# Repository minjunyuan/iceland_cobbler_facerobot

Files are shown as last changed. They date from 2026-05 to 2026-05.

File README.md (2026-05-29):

# Iceland Cobbler Face Robot

这是一个基于 Blender 开源角色模型进行二次设计的人脸机器人项目。项目内容包括机器人内部表情机构、脸部外壳、硅胶皮肤模具，以及用于展示的 STL 文件。

除明确注明来源的 Blender Studio Einar 参考模型外，本文展示的机器人机械结构、外壳、硅胶皮肤模具和实物制作均为自制。机构驱动舵机使用 MG90D。

## 项目状态

本文主要记录设计思路、关键流程和阶段性成果，没有对内部结构设计的全部细节逐一展开。若对某个结构、制作步骤或文件内容有疑问，可以通过 GitHub Issues 交流。

实际制作人脸机器人时会遇到大量与材料、装配公差、驱动行程、硅胶成型和外壳避让相关的具体问题，需要读者结合自己的加工条件和设计目标自行调整。本项目目前处于搁置状态，现有结构仍存在一些需要继续优化的问题，但整体设计方向接近常见人脸机器人和仿生表情机构的主流思路，可作为外观机构、面壳设计和硅胶模具设计的参考案例。

## 项目结构

```text
.
├─ full_assembly_stl/   # 所有设计元素的 STL 文件
├─ images/              # 项目图片、渲染图、过程图
└─ README.md
```

## 1. 设计对象

本项目的设计对象来源于 Blender Studio 的开源角色模型：[Einar](https://studio.blender.org/characters/einar/v1/)。

这个模型本身有完整的头部建模，并且包含独立的眼睛、牙齿和舌头模型。由于这些部分之间的相对位置已经确定，因此非常适合作为人脸机器人外观设计、机构空间规划和硅胶皮肤制作的参考对象。

<p>
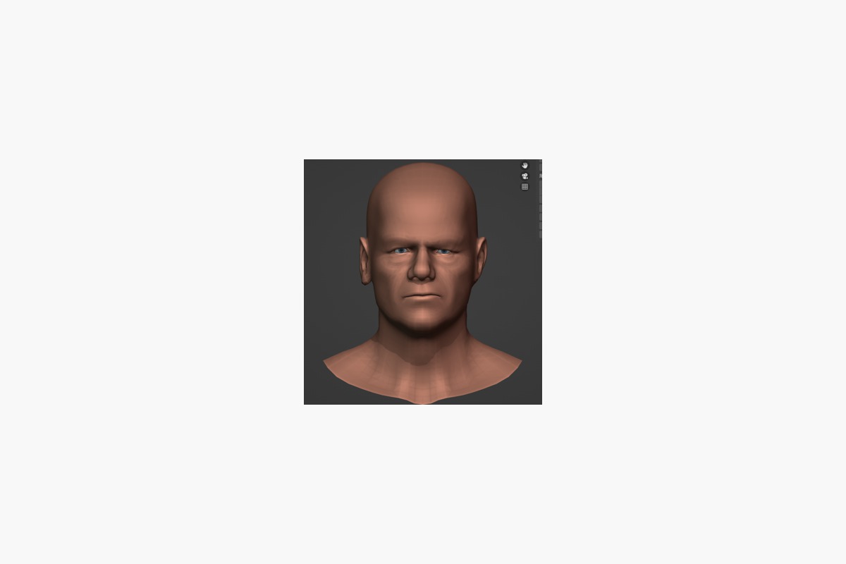
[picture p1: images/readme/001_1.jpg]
Einar 参考图 1
  
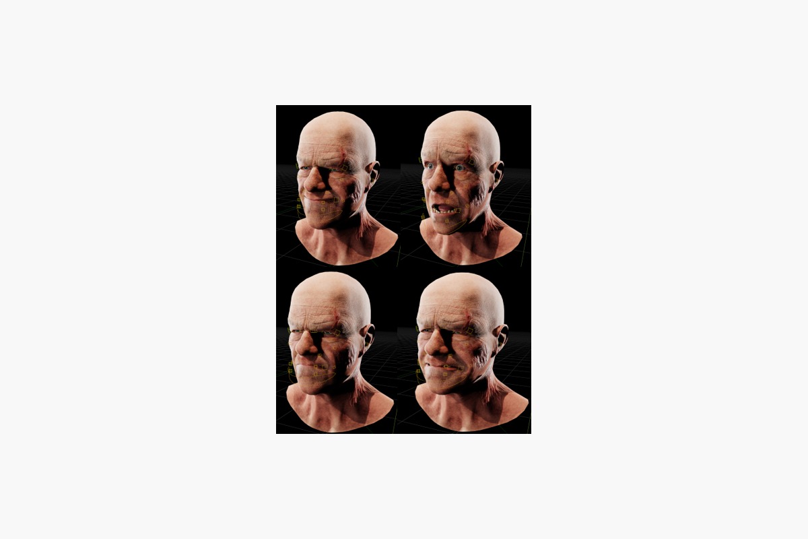
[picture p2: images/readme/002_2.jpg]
Einar 参考图 2
  
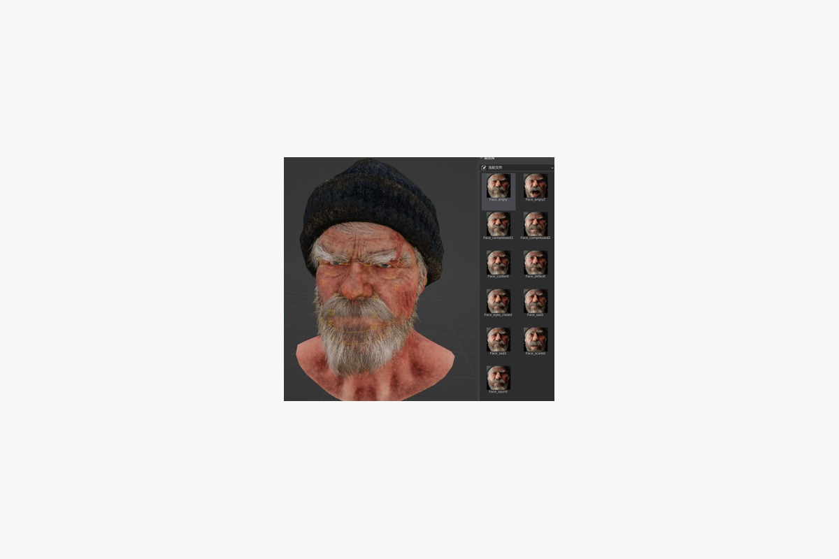
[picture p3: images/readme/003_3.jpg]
Einar 参考图 3
  
</p>

<p>
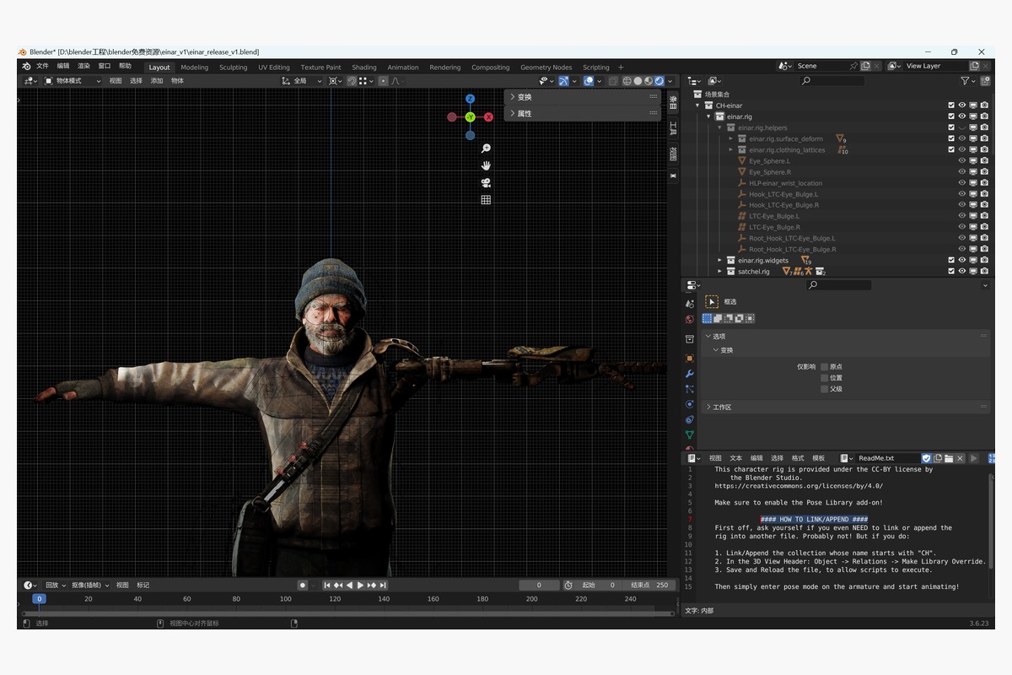
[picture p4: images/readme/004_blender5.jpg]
Blender 参考模型 1
  
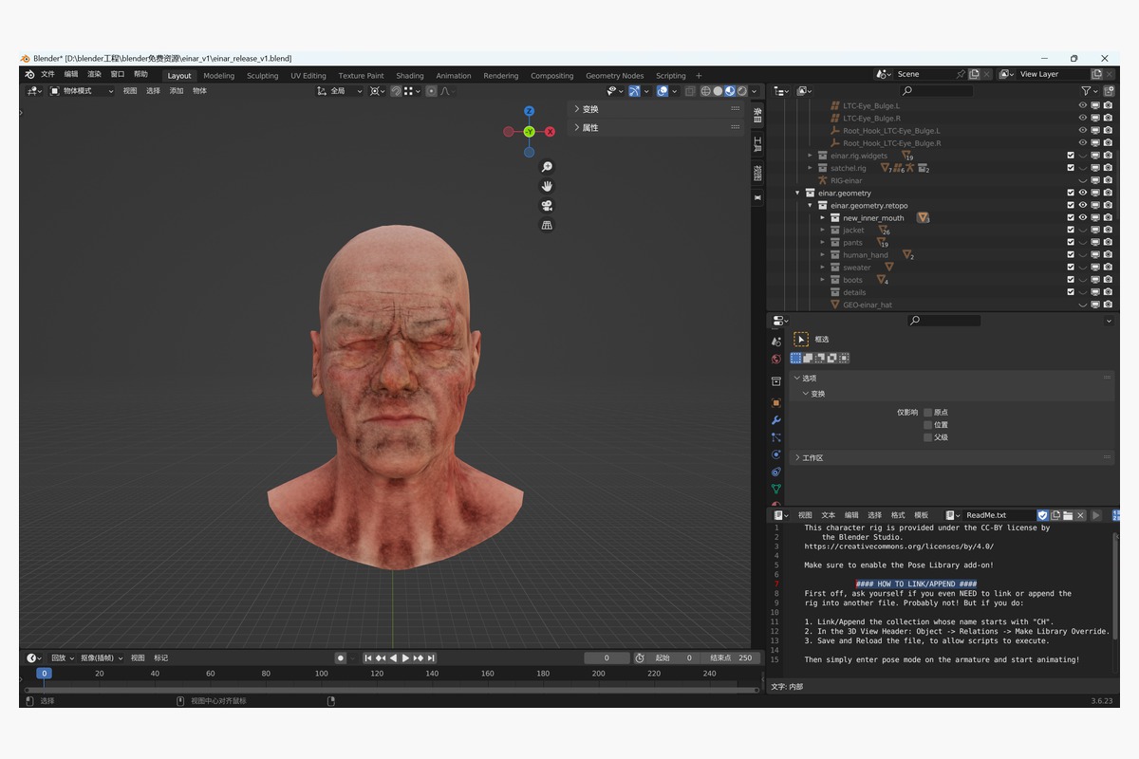
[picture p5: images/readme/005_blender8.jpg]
Blender 参考模型 2
  
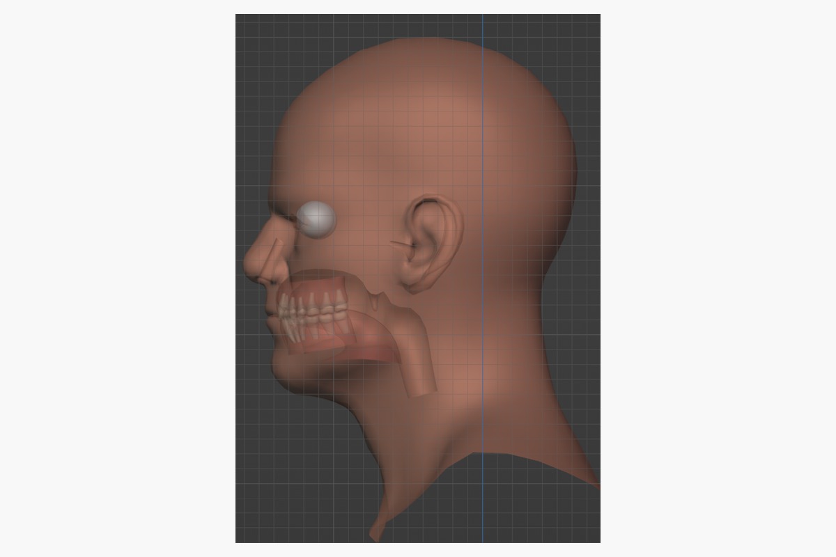
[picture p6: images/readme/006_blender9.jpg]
Blender 参考模型 3
  
</p>

## 2. 结构设计

结构部分采用模块化设计，目的是方便拆装、调试和后续修改。主体可以分为眉部、眼部和嘴部，其中嘴部又分为上颚部分和下颚部分。

眉部机构会预留一部分脸颊和鼻子拉线的空间；眼部机构用于支撑和控制眼睛区域；嘴部机构则承担上下颚和口腔区域的表情运动。

本项目中使用的舵机型号为 MG90D。模块化设计可以让舵机、连杆、壳体和硅胶皮肤的设计相互独立，便于单独修改和迭代。

### 整体设计展示

<p>
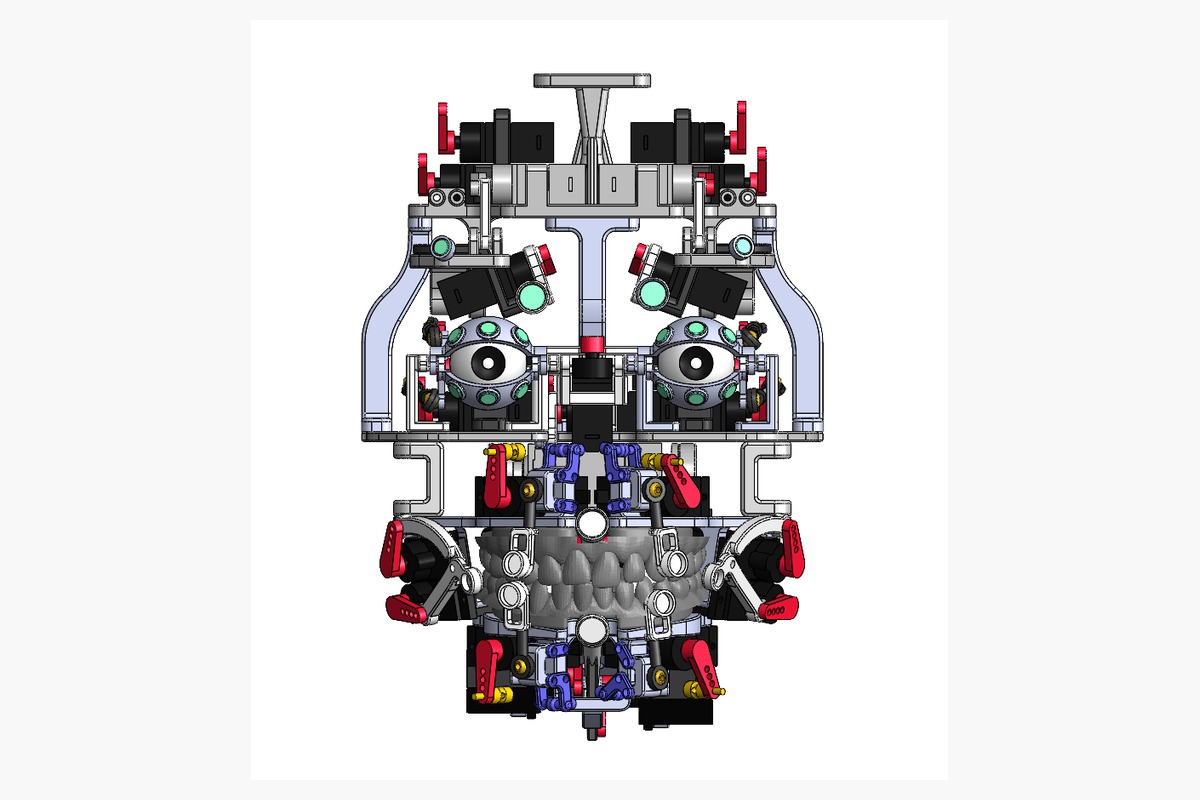
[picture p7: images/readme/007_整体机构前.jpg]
整体机构前视图
  
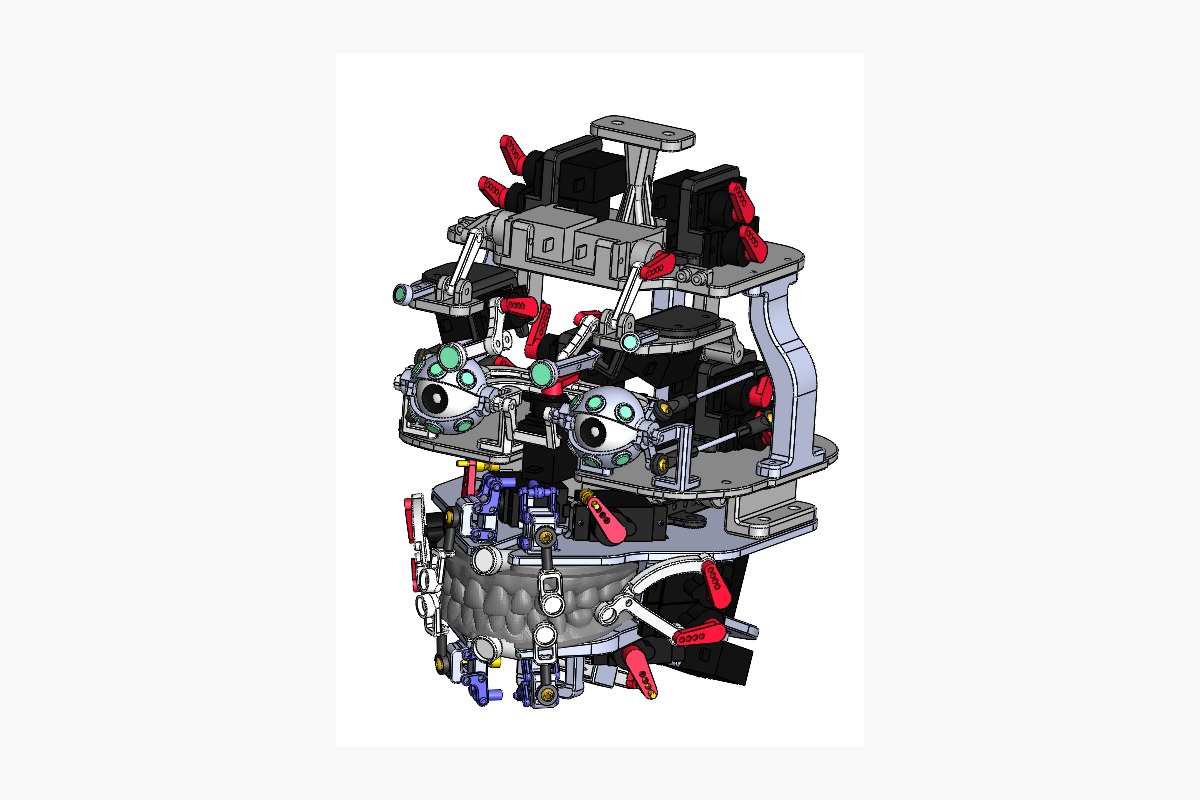
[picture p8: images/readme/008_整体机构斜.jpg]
整体机构斜视图
  
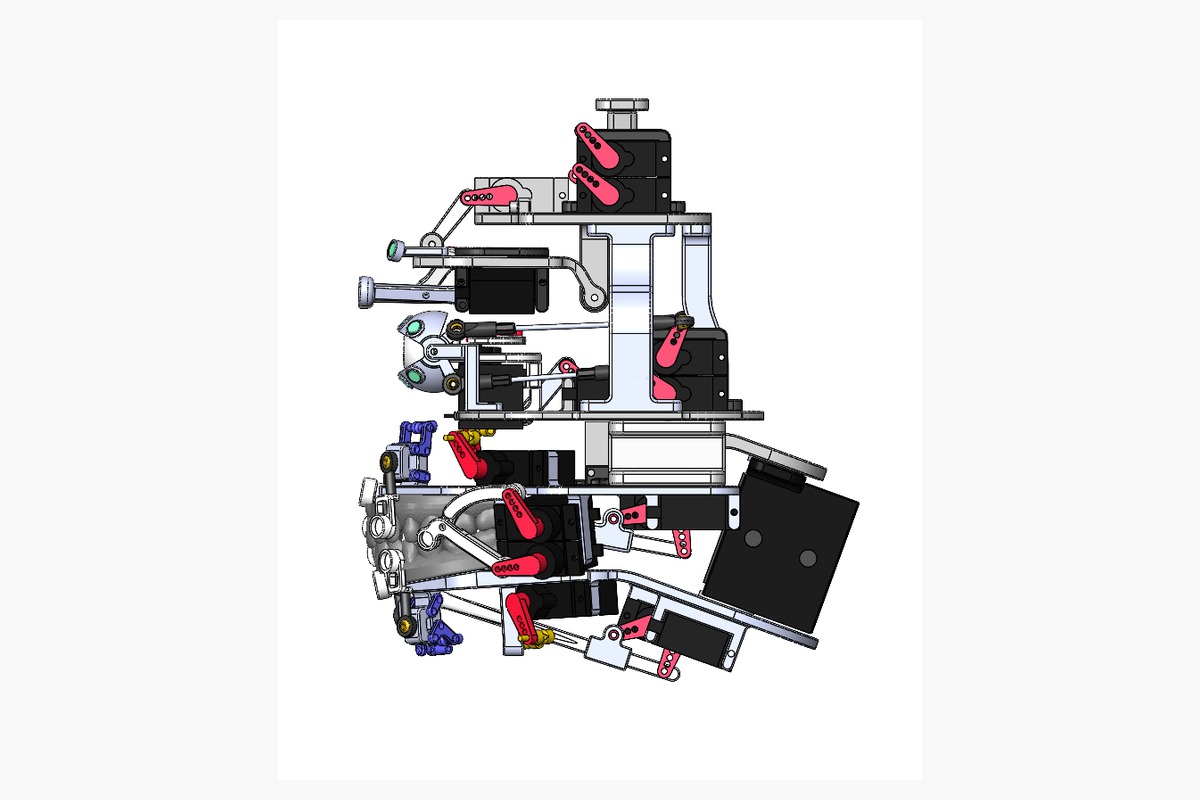
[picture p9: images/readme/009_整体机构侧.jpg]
整体机构侧视图
  
</p>

<p>
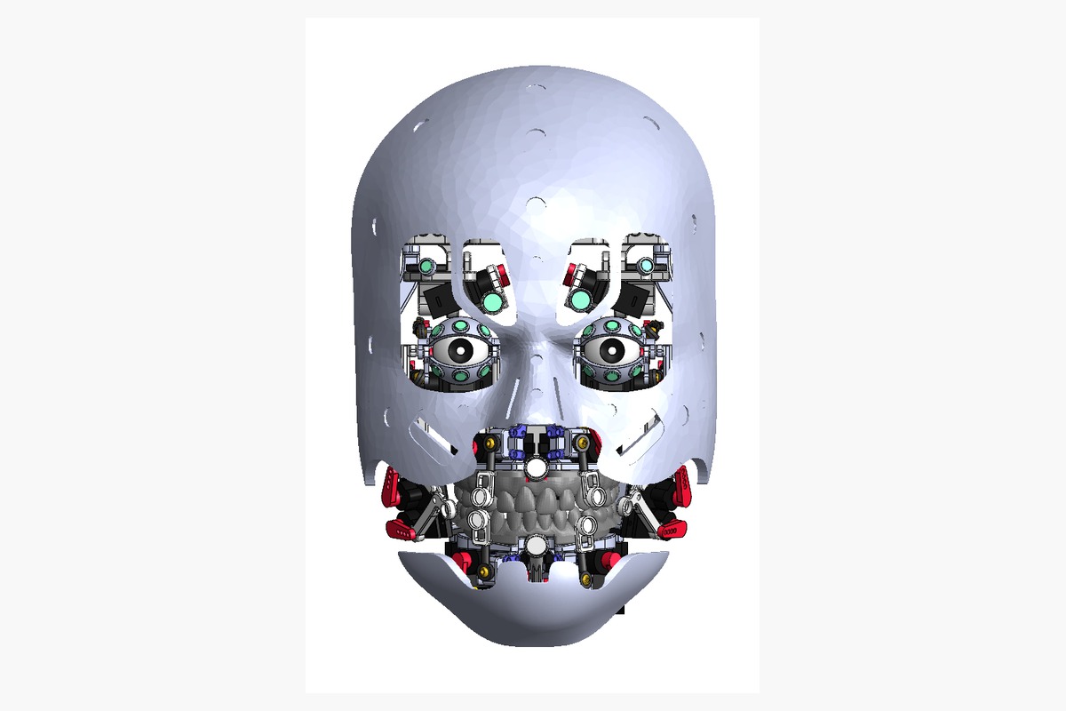
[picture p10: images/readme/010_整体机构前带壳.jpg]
整体机构前视图带壳
  
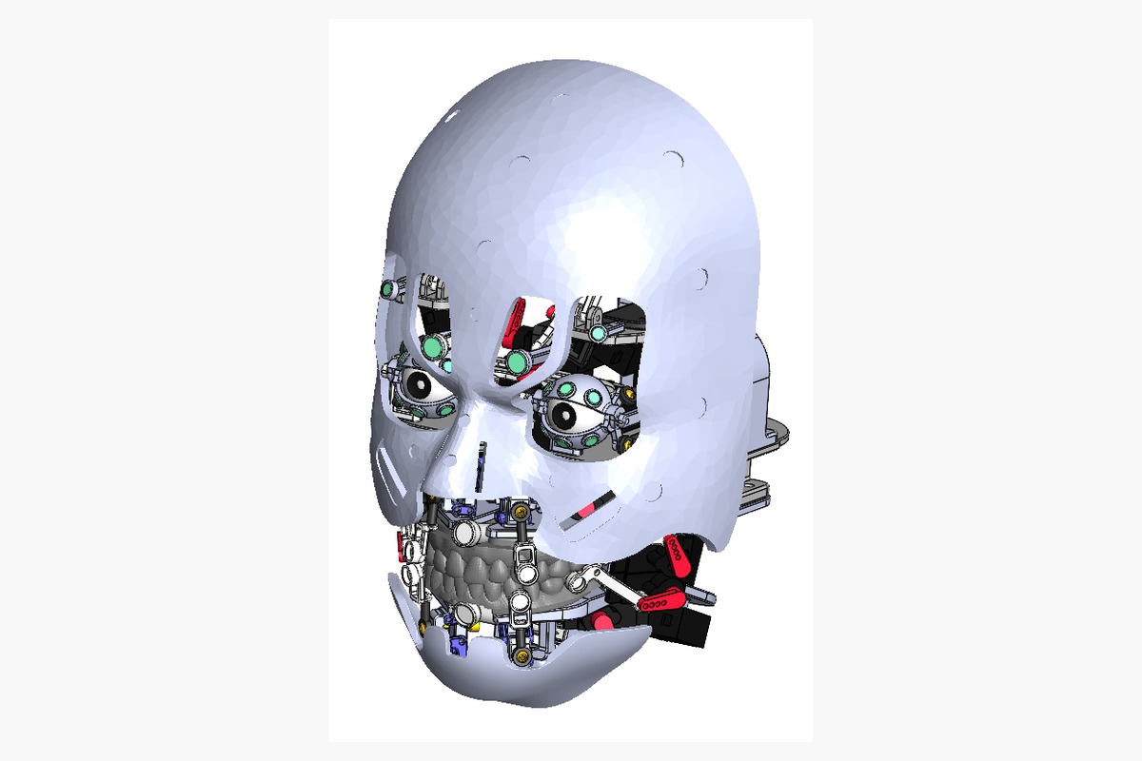
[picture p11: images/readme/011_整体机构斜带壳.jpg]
整体机构斜视图带壳
  
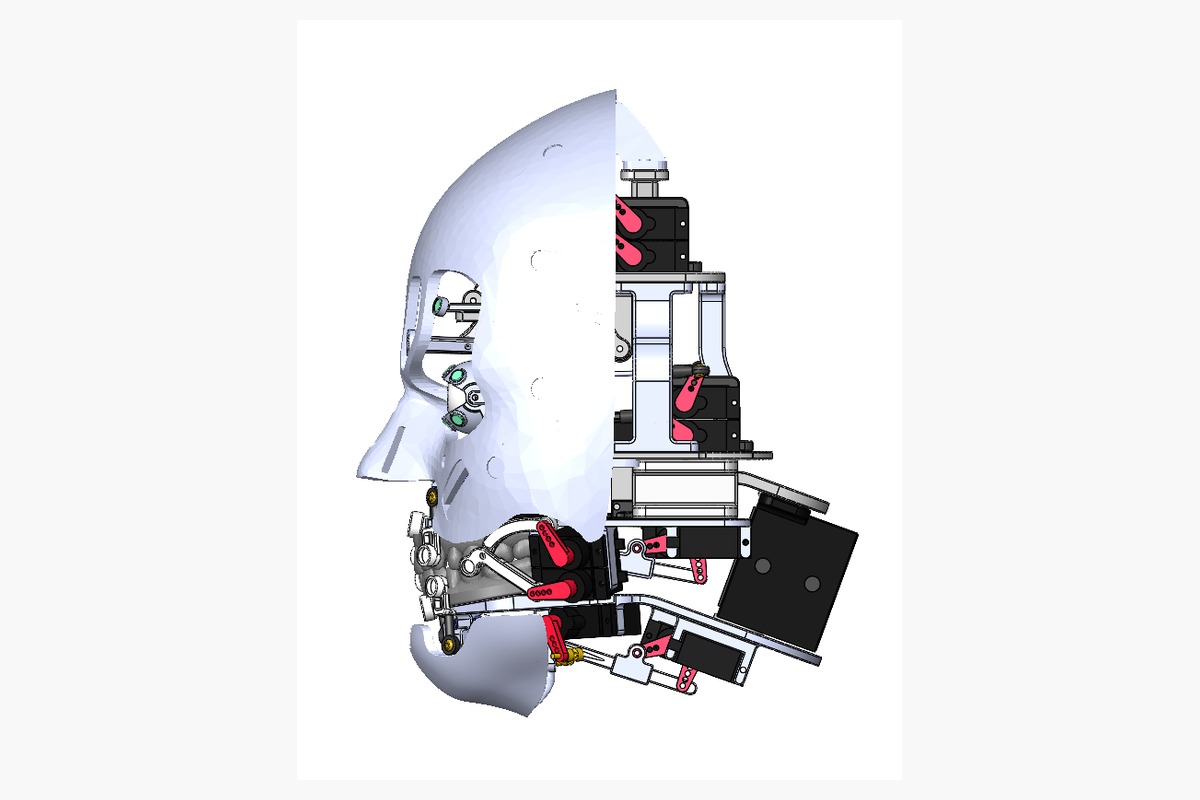
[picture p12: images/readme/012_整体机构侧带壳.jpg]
整体机构侧视图带壳
  
</p>

<p>
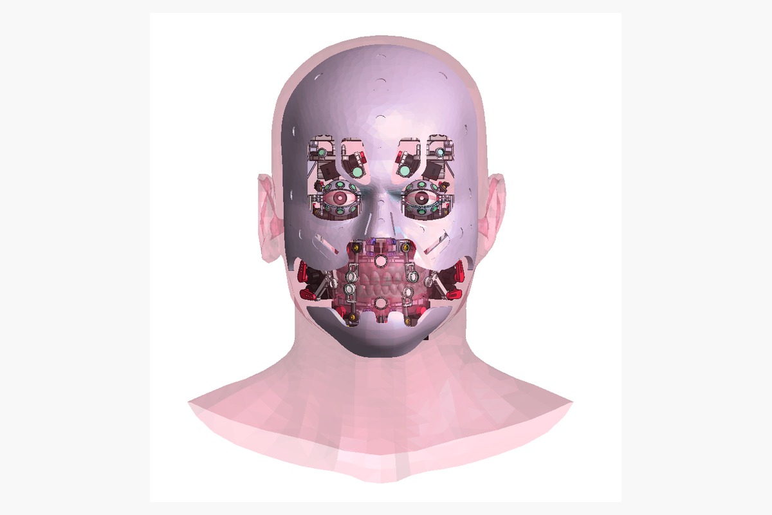
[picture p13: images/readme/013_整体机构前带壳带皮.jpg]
整体机构前视图带壳带皮
  
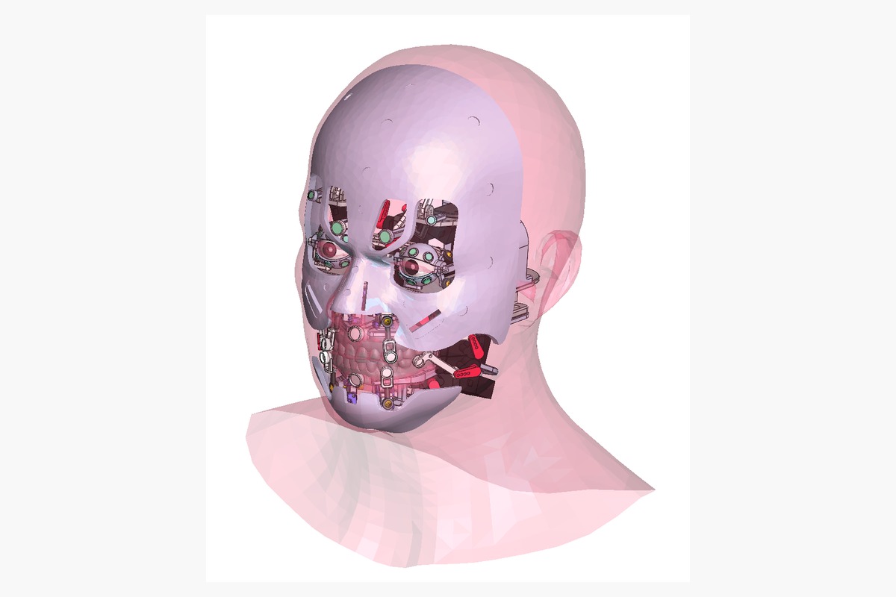
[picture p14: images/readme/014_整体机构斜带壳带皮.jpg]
整体机构斜视图带壳带皮
  
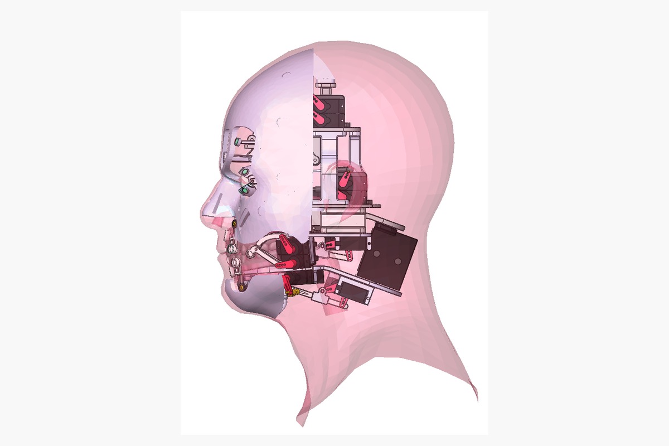
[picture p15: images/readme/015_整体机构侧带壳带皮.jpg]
整体机构侧视图带壳带皮
  
</p>

### 眉部机构

<p>
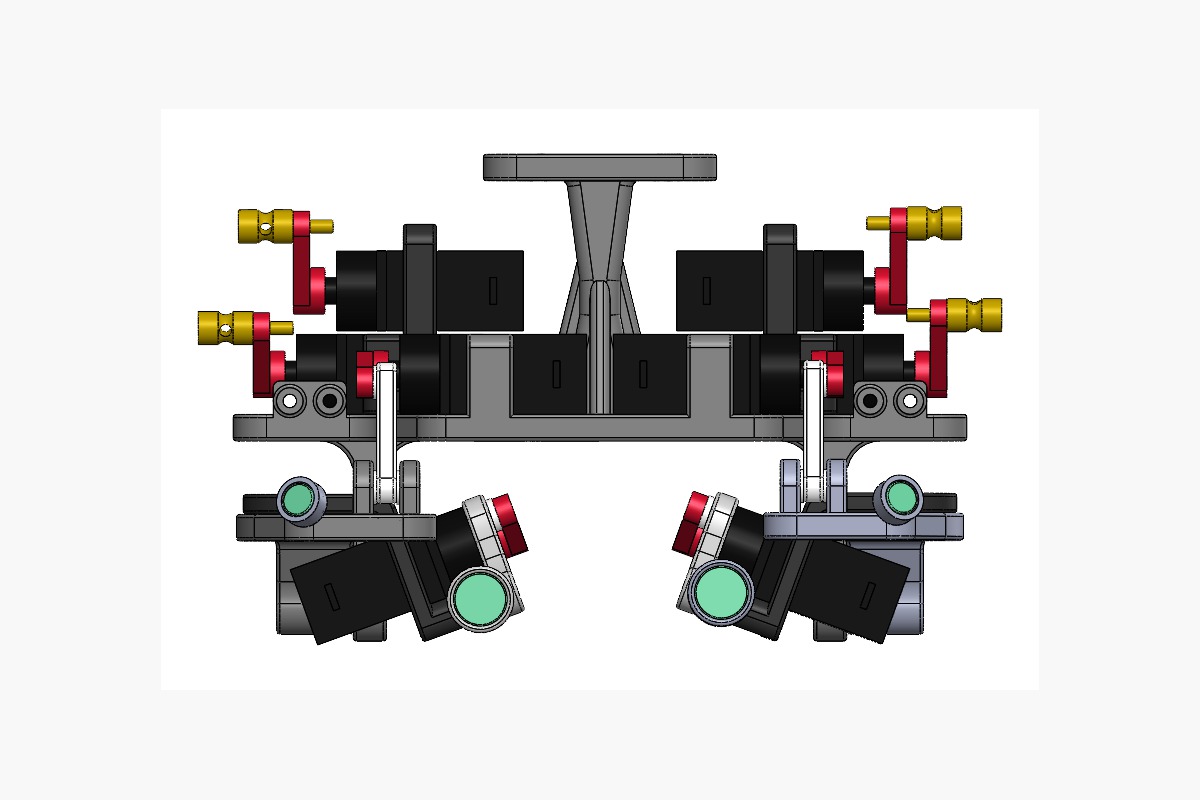
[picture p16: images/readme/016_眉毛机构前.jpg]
眉毛机构前视图
  
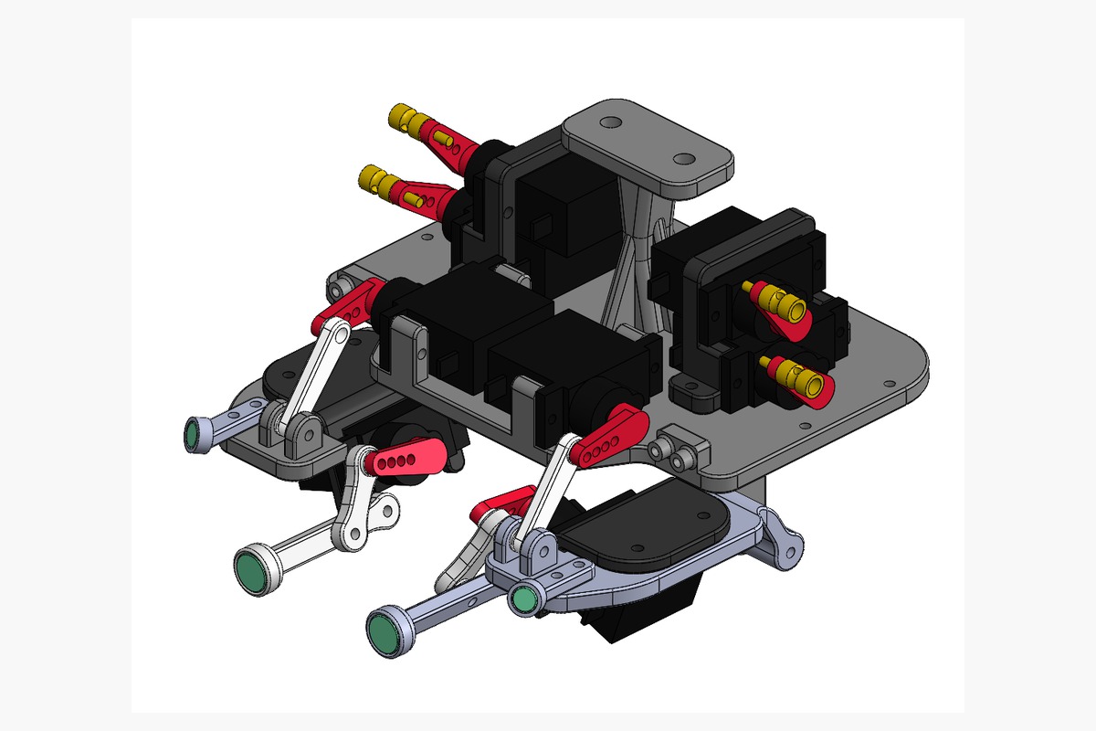
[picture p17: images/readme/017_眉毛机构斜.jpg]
眉毛机构斜视图
  
</p>

### 眼部机构

<p>
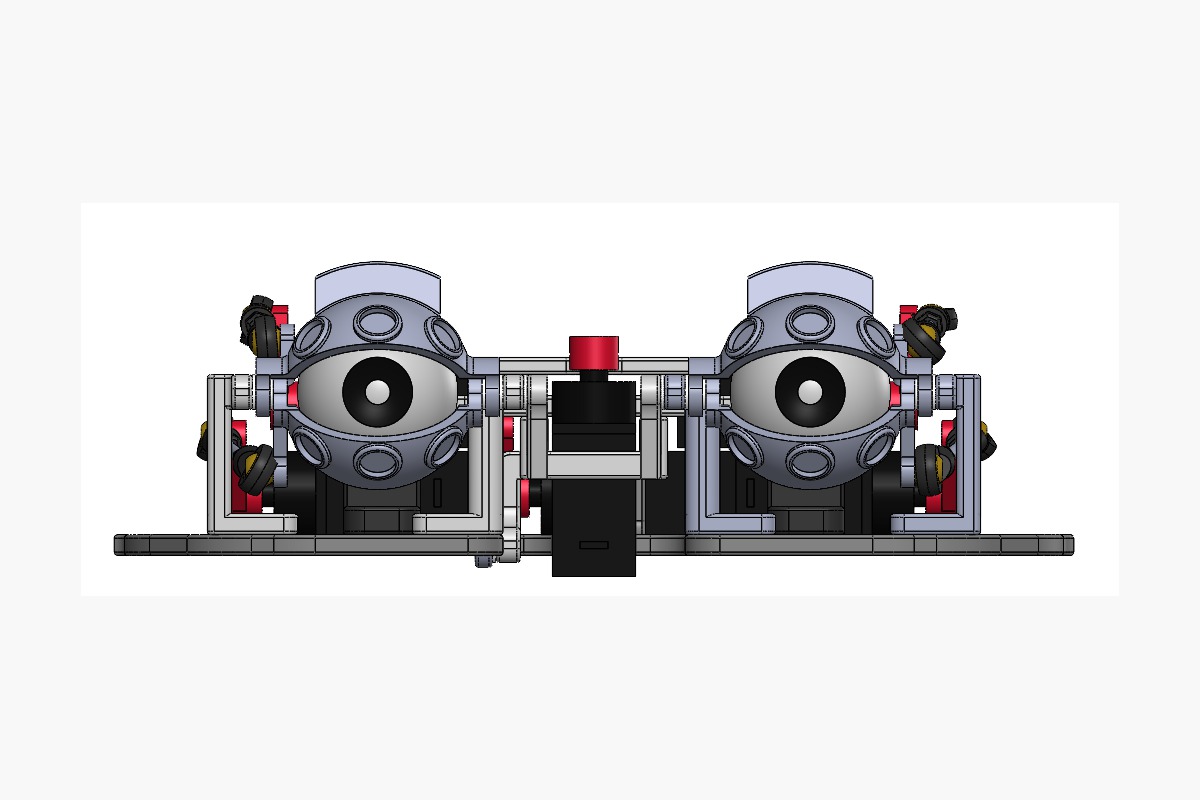
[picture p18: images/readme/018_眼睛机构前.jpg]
眼睛机构前视图
  
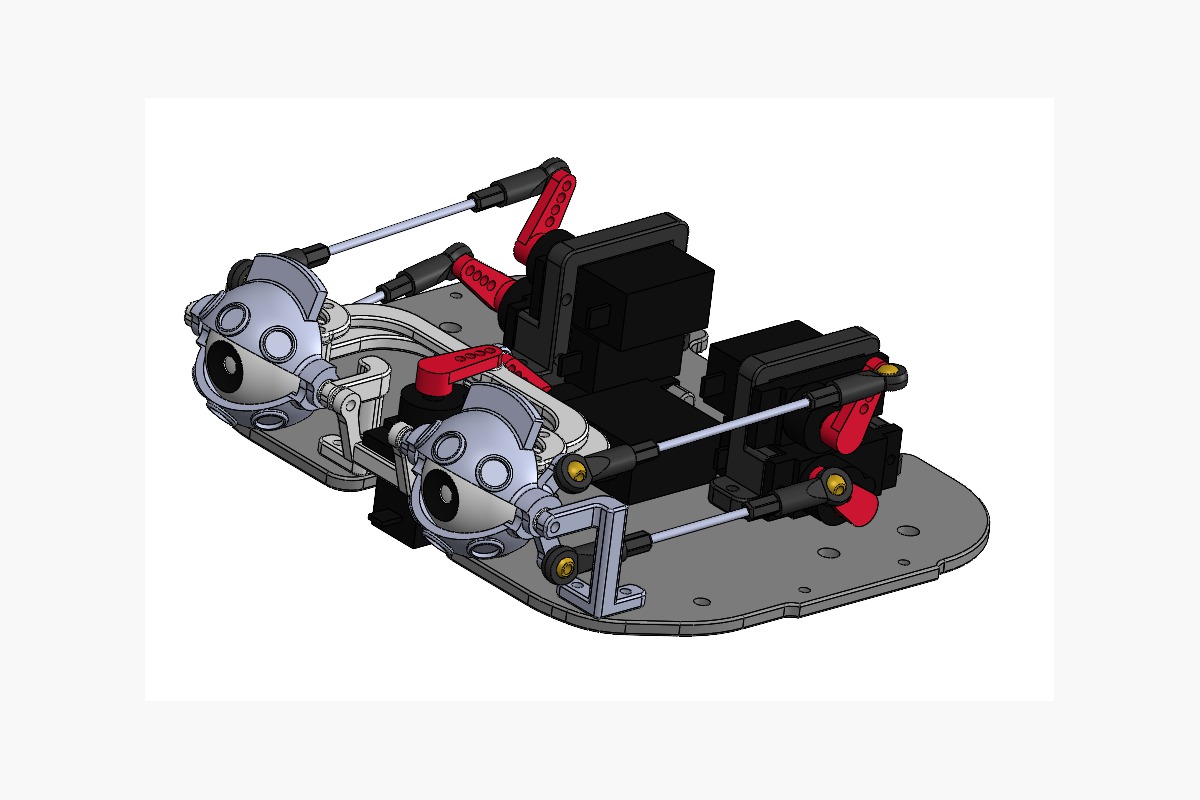
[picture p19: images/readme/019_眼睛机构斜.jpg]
眼睛机构斜视图
  
</p>

### 嘴部机构

<p>
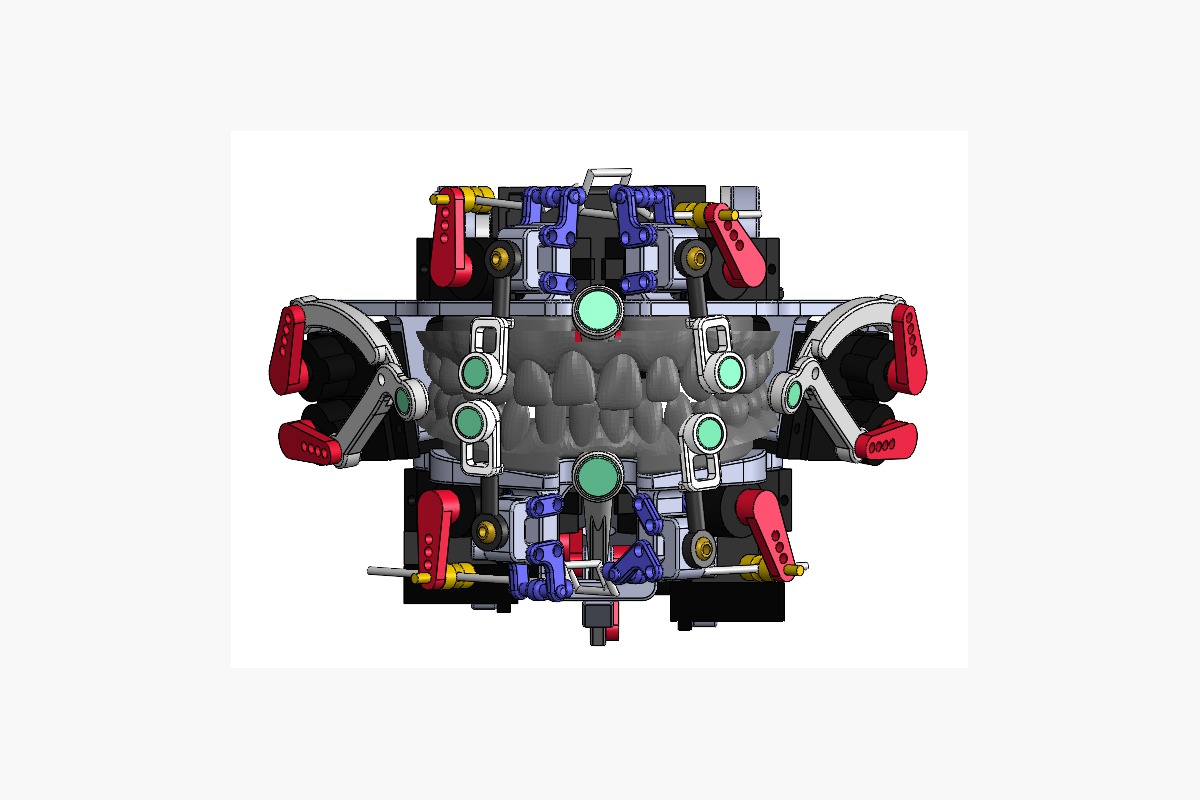
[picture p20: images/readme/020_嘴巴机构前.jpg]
嘴巴机构前视图
  
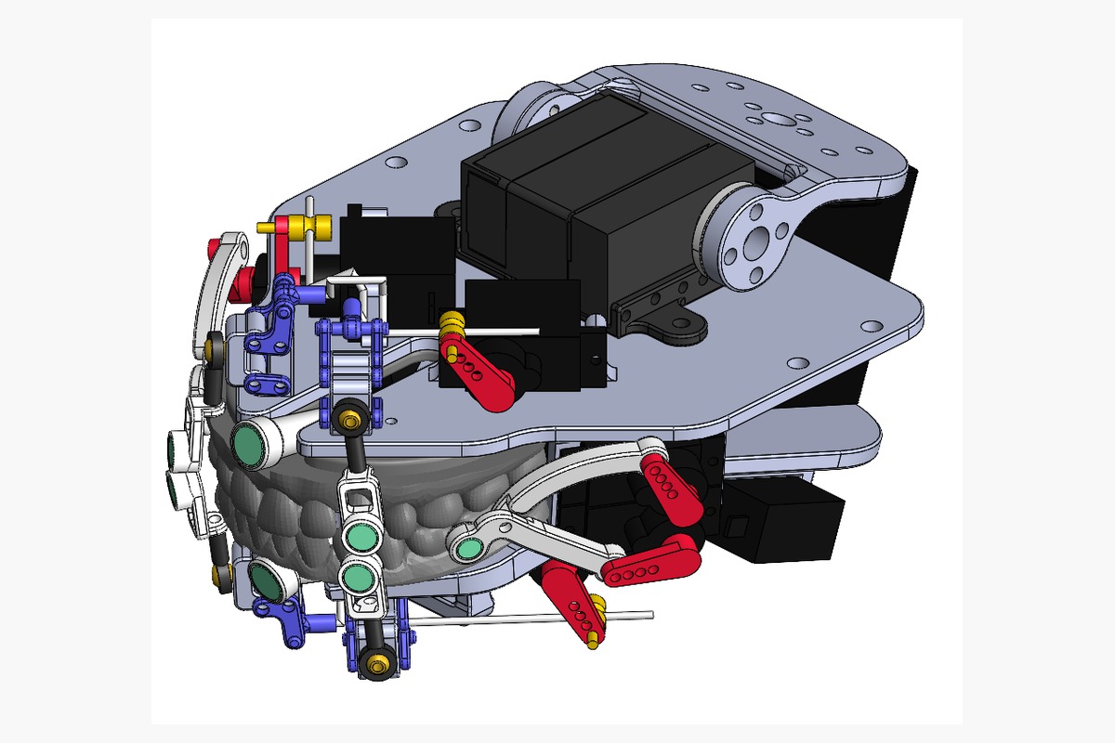
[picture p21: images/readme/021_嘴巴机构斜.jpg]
嘴巴机构斜视图
  
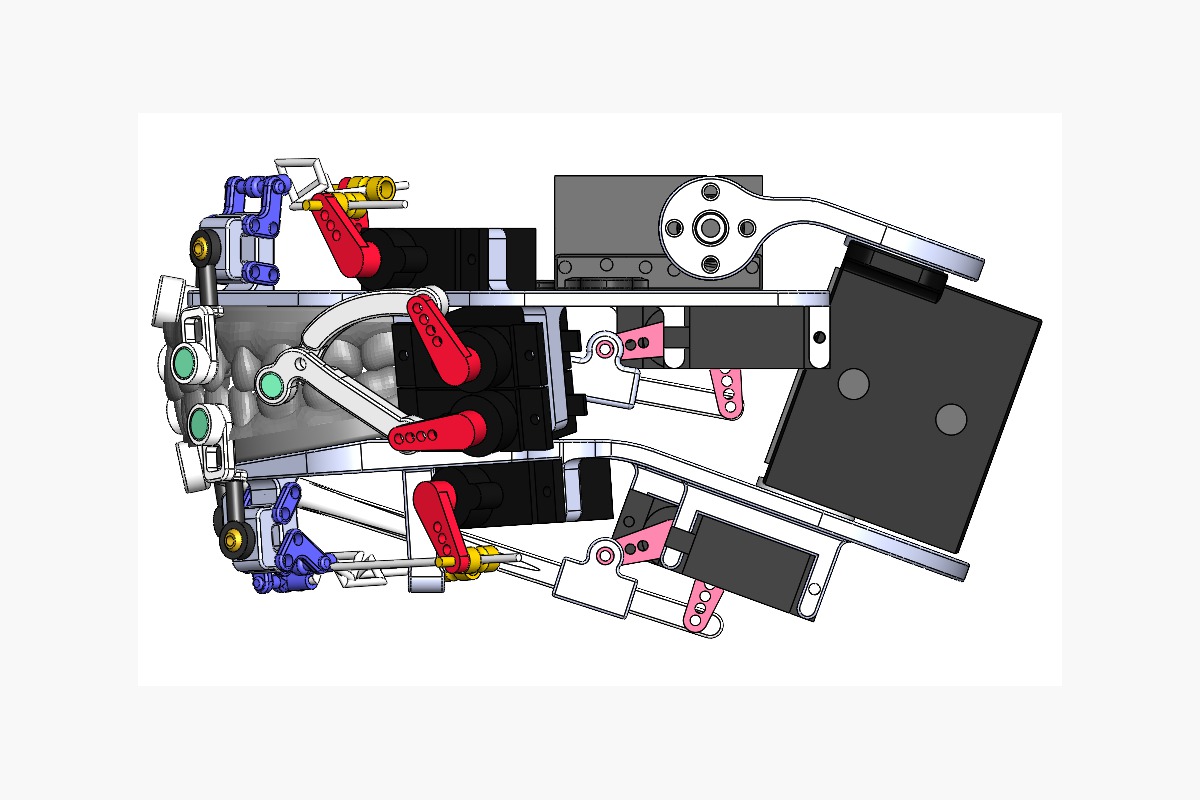
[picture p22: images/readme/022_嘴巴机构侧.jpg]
嘴巴机构侧视图
  
</p>

### 实物图

<p>
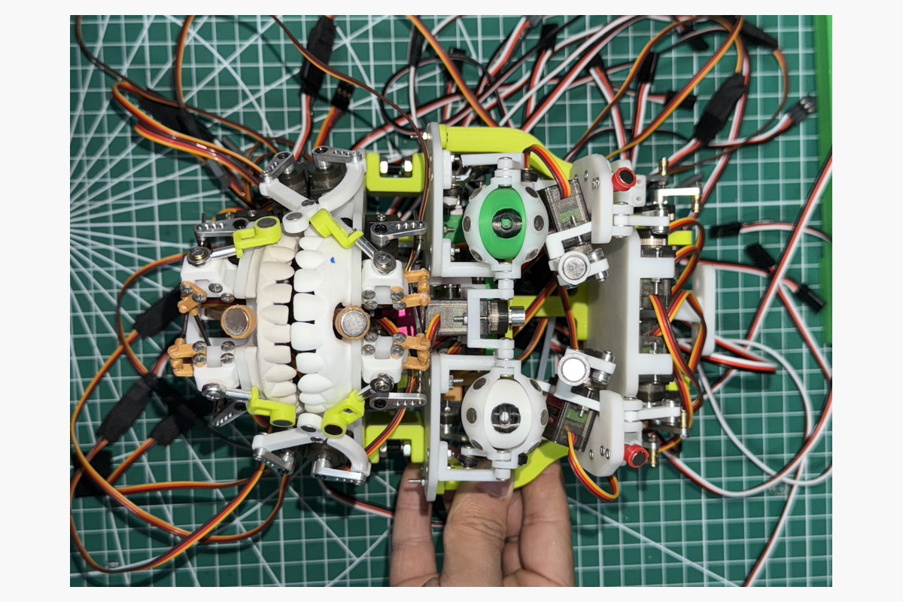
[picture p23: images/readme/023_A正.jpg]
实物图 A 正面
  
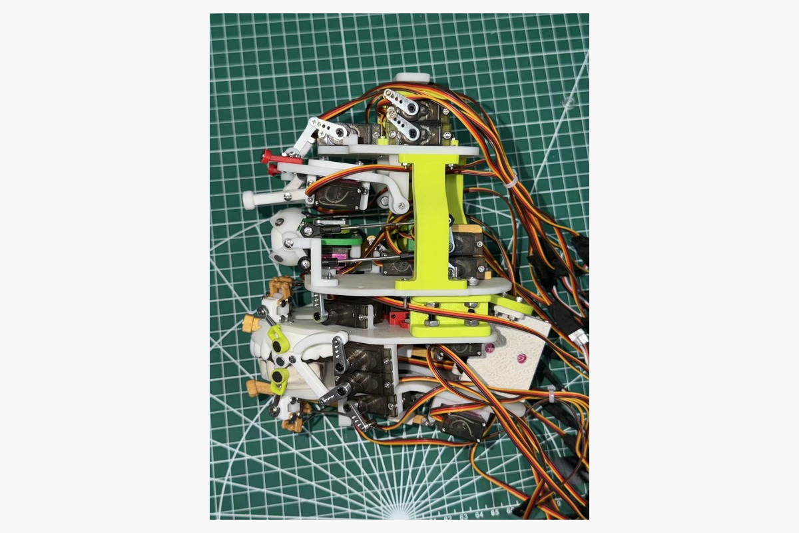
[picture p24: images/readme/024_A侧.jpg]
实物图 A 侧面
  
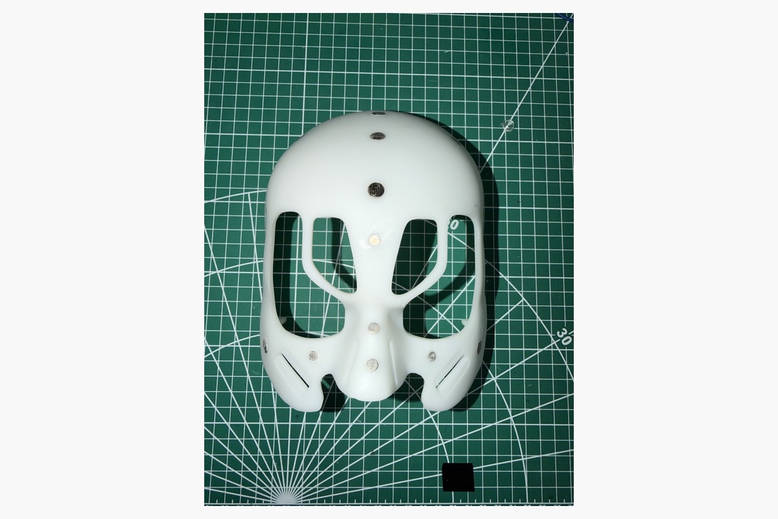
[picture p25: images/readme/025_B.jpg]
实物图 B
  
</p>

### STL 文件说明

`full_assembly_stl/` 中放置了所有设计元素的 STL 文件。将这些 STL 导入任何可以观察 STL 的软件中，例如 Blender，可以显示正确的相对位置。

在本项目中，Blender 不只是展示工具，后续也用于设计机器人脸部外壳，以及设计硅胶皮肤制作所需要的模具。

<p>
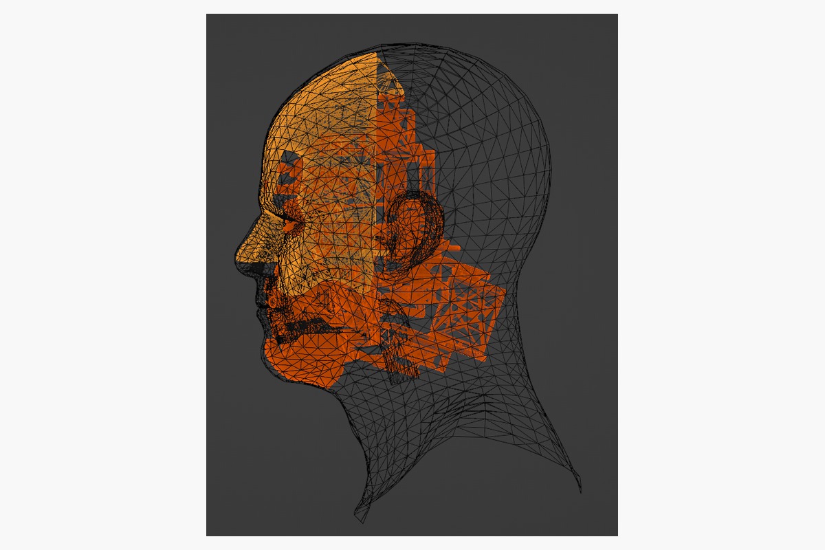
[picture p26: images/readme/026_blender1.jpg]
STL 导入 Blender 1
  
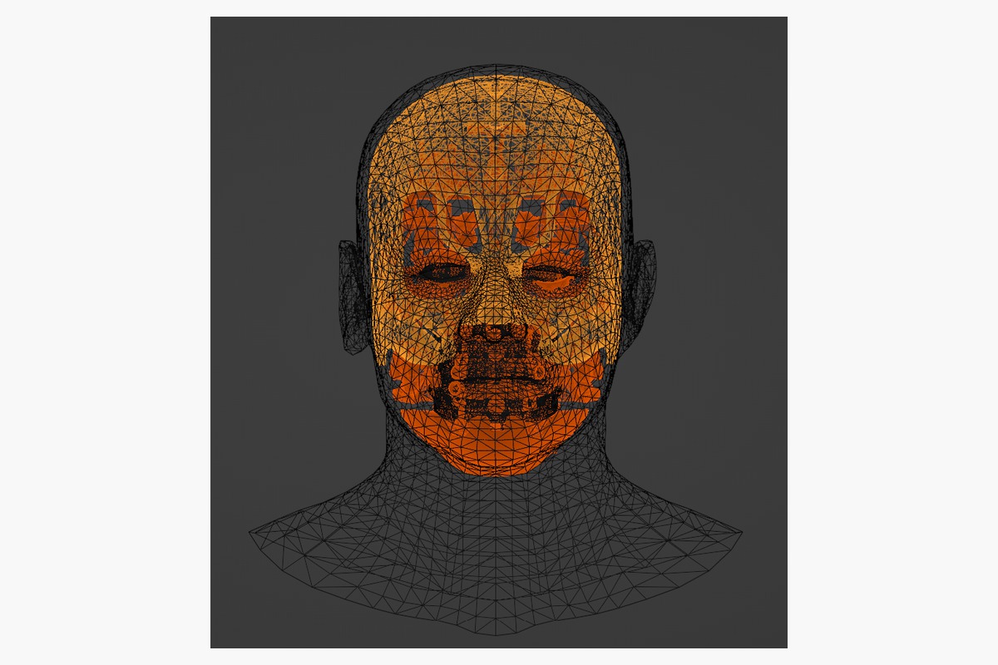
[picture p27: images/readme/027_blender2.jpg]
STL 导入 Blender 2
  
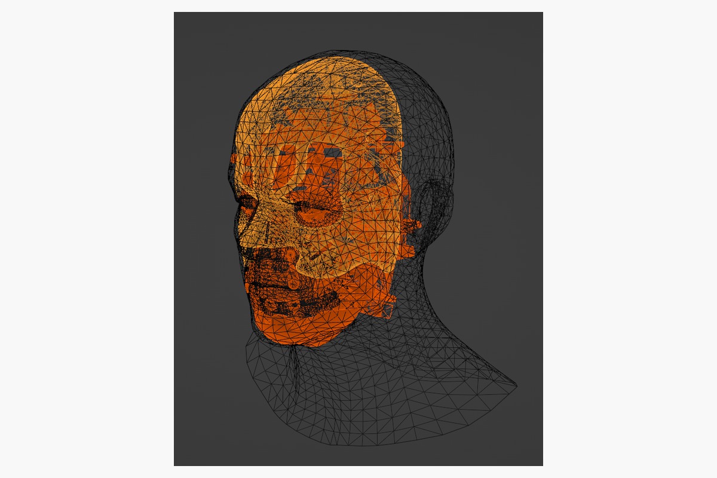
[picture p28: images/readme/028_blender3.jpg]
STL 导入 Blender 3
  
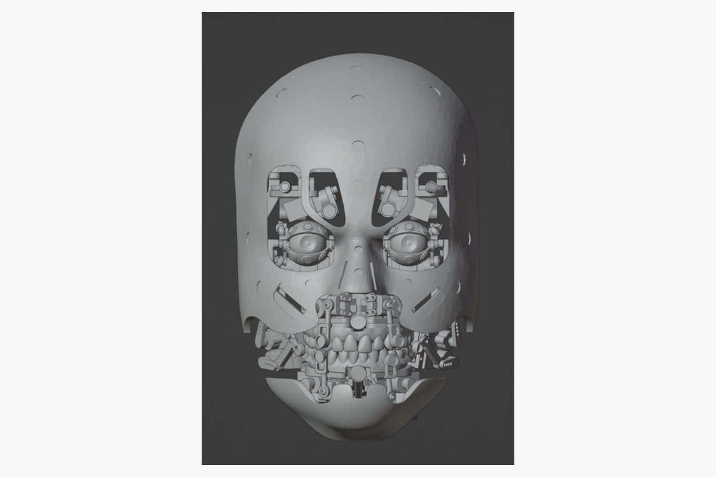
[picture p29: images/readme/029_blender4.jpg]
STL 导入 Blender 4
  
</p>

## 3. 机器人脸部外壳设计（Blender）

### 3.1 参考人物模型处理

Blender 开源模型中可以获得无厚度的参考人物模型。机器人脸部外壳不需要明显的皱纹，同时对称、平整的表面更适合后续设计和加工，所以这里对原始模型进行了平滑处理。

<p>
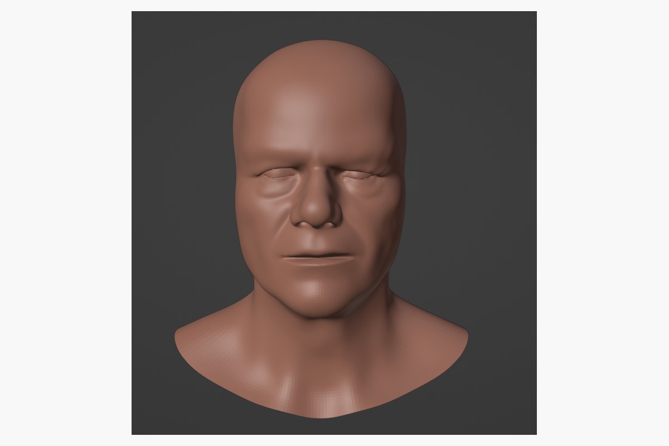
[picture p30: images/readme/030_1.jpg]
参考模型处理 1
  
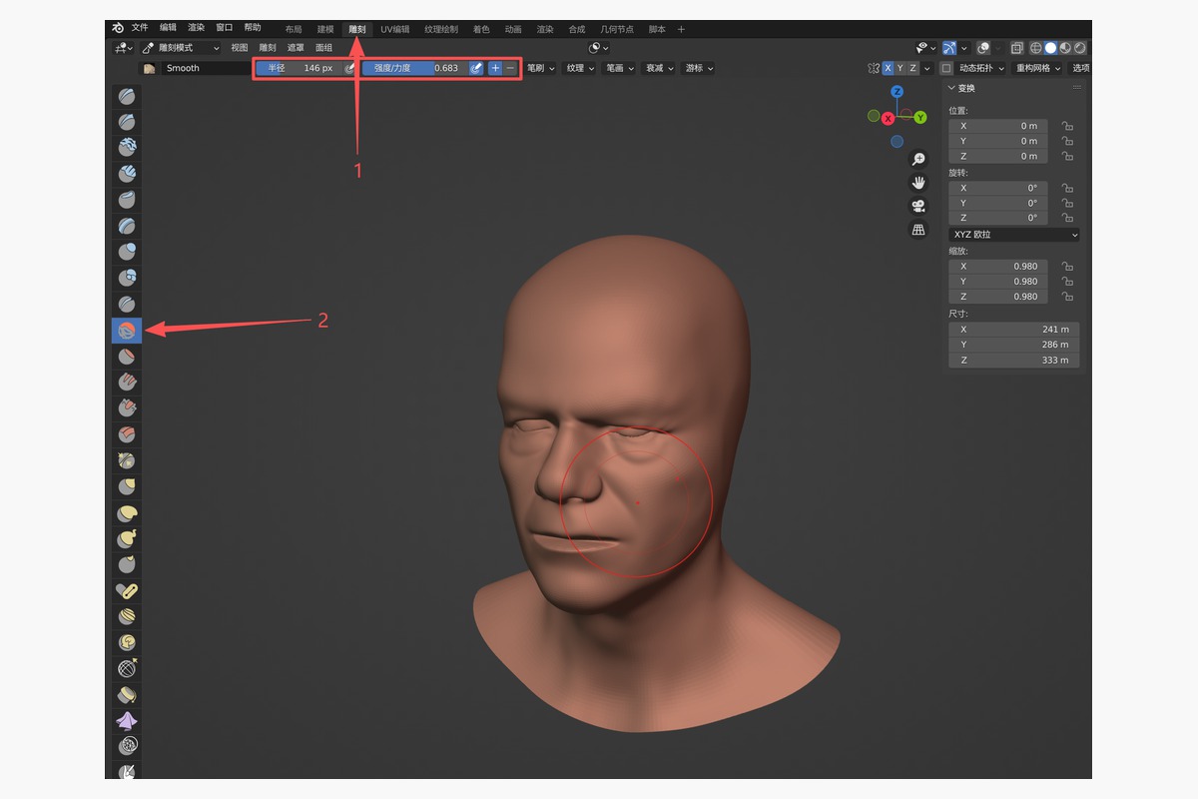
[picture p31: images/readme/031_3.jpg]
参考模型处理 2
  
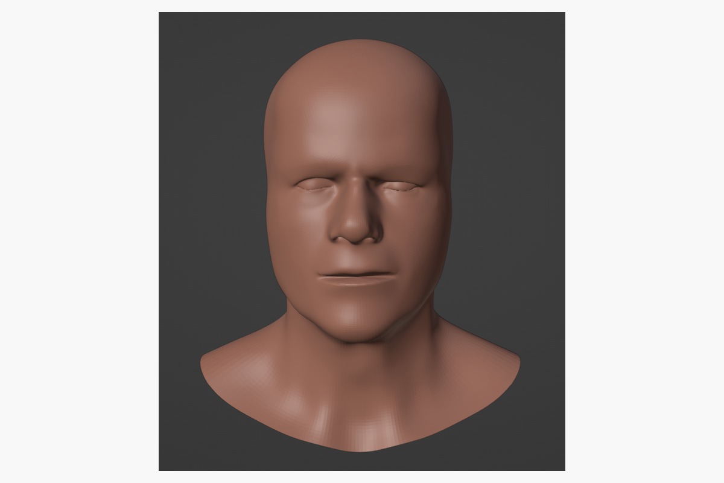
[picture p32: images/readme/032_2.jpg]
参考模型处理 3
  
</p>

### 3.2 外壳厚度

外壳需要一定厚度。在 Blender 中，固定厚度通常可以通过修改器中的“实体化”完成，厚度选项可以修改壳体厚度，偏移量可以决定实体化方向。

需要注意两点：

- Blender 中的单位 `m` 在当前显示中对应 `mm`。
- 有些区域，例如眼睛附近，曲率比较大，实体化后可能出现局部穿模。但在制作外壳时不一定需要担心，因为这些区域后续通常会被挖掉，用来给运动构件留空间。

<p>
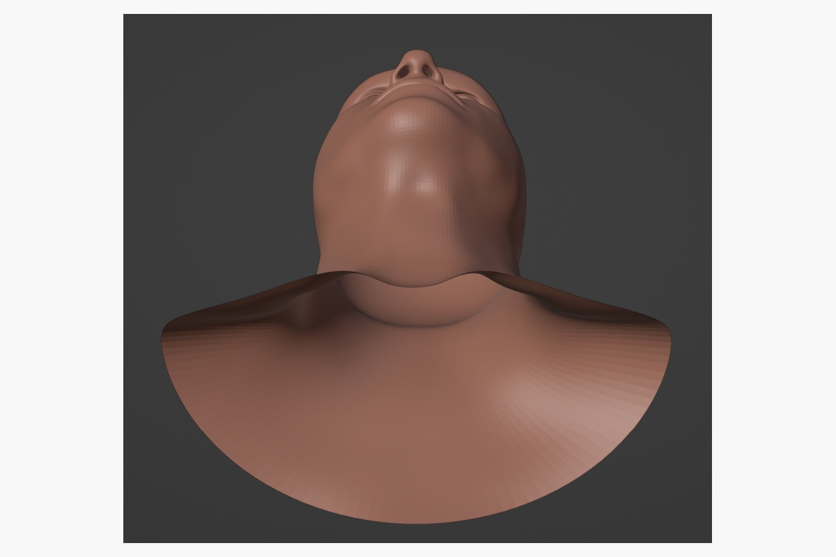
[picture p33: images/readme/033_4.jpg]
实体化厚度 1
  
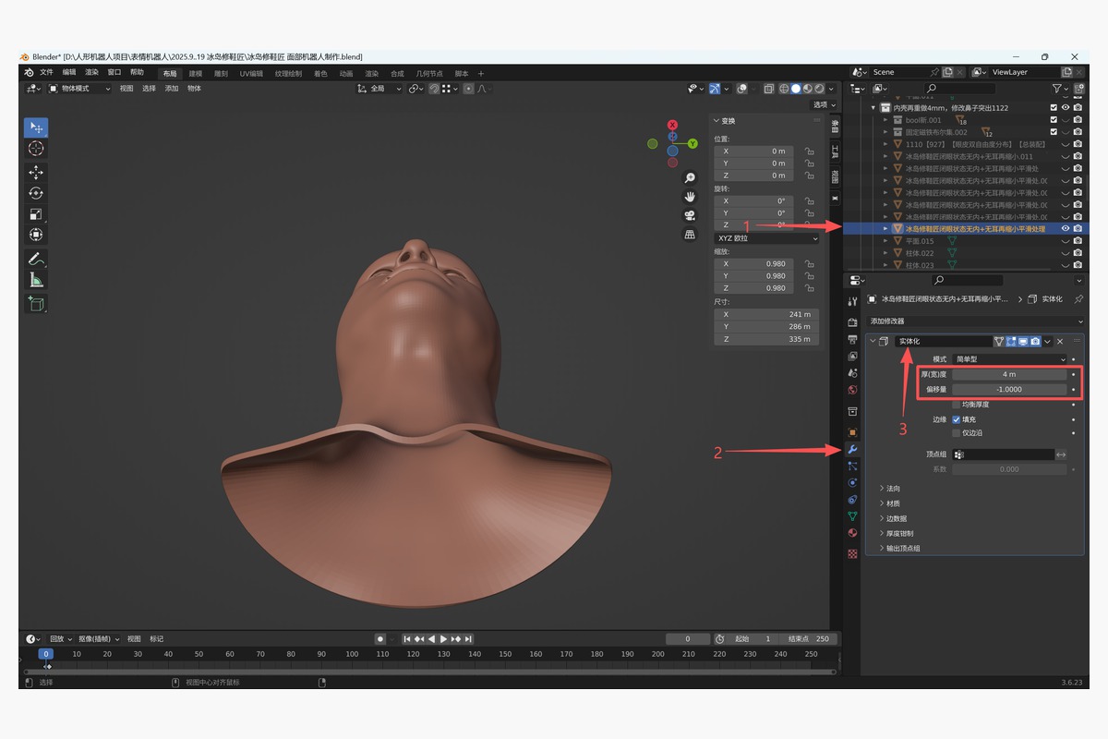
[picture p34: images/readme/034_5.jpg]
实体化厚度 2
  
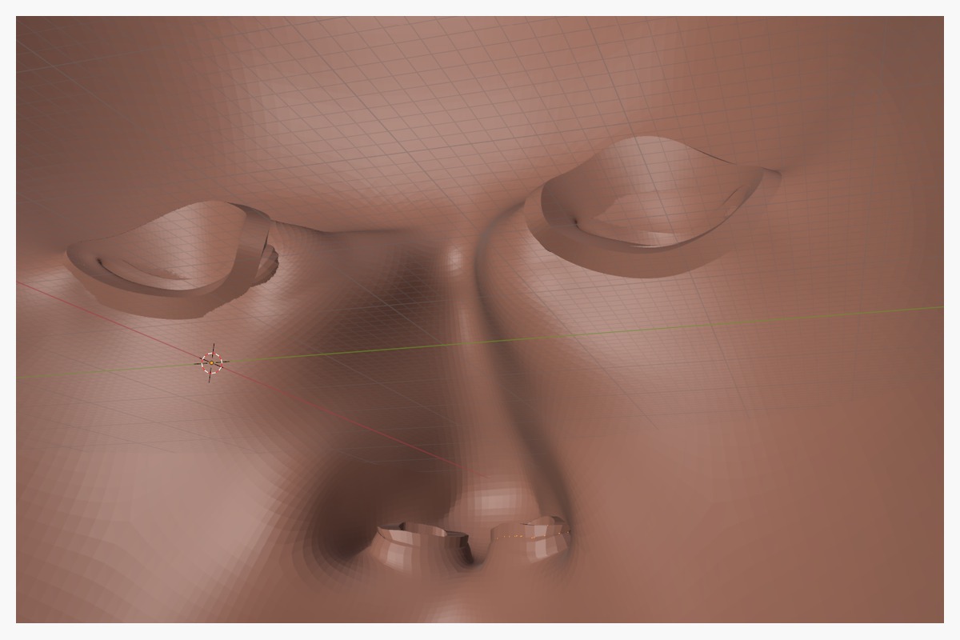
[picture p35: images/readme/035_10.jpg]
实体化厚度 3
  
</p>

### 3.3 外壳制作

#### 布尔修改器演示

在机器人驱动位置的外壳处，需要给内部运动机构让出空间。本项目主要依靠 Blender 的布尔修改器完成切割。

基本思路是：在对应角度画出想切割的切面，封闭网格后，按 `E` 将切割体延伸至与模型相交，然后添加布尔修改器，即可删去对应区域。

<p>
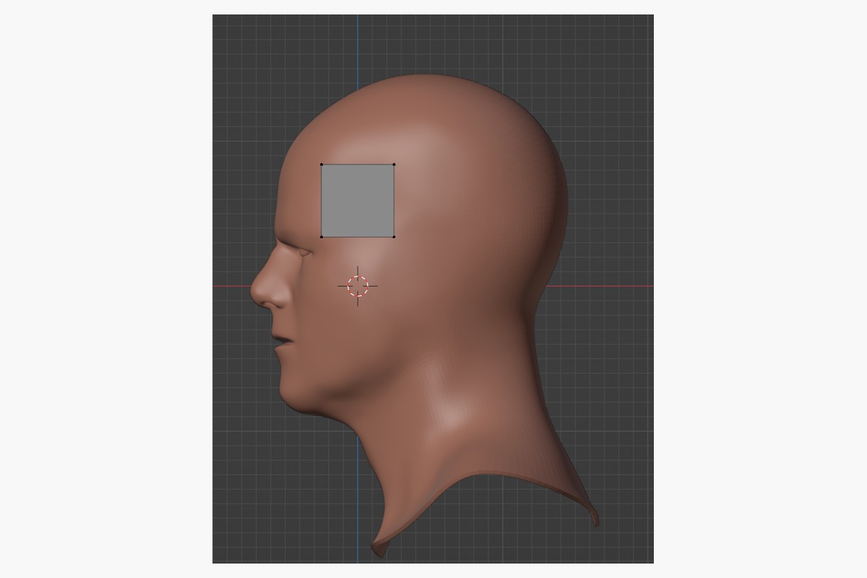
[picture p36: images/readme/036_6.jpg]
布尔修改器演示 1
  
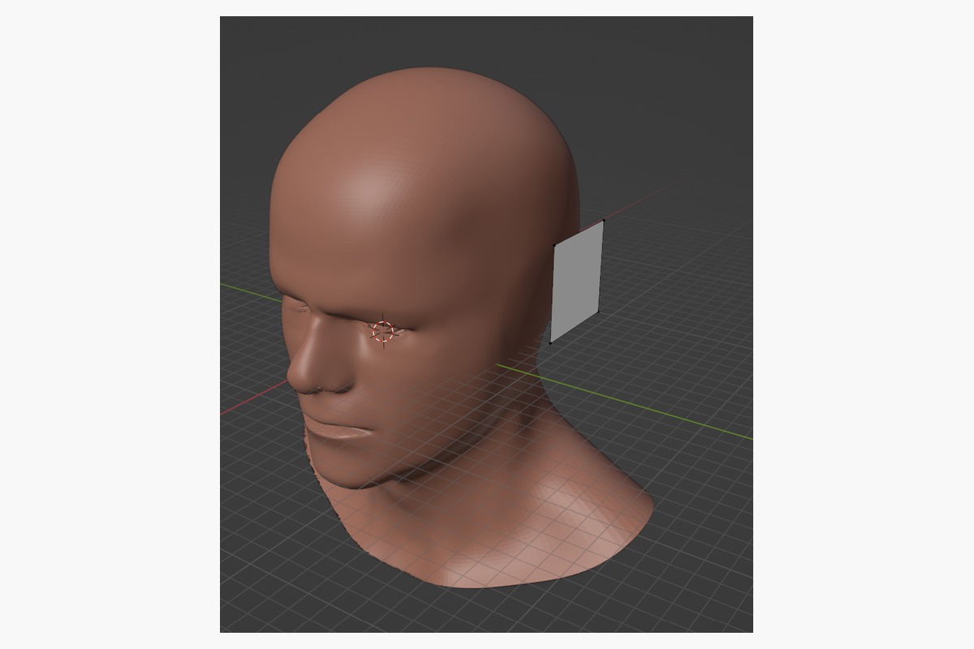
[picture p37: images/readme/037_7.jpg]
布尔修改器演示 2
  
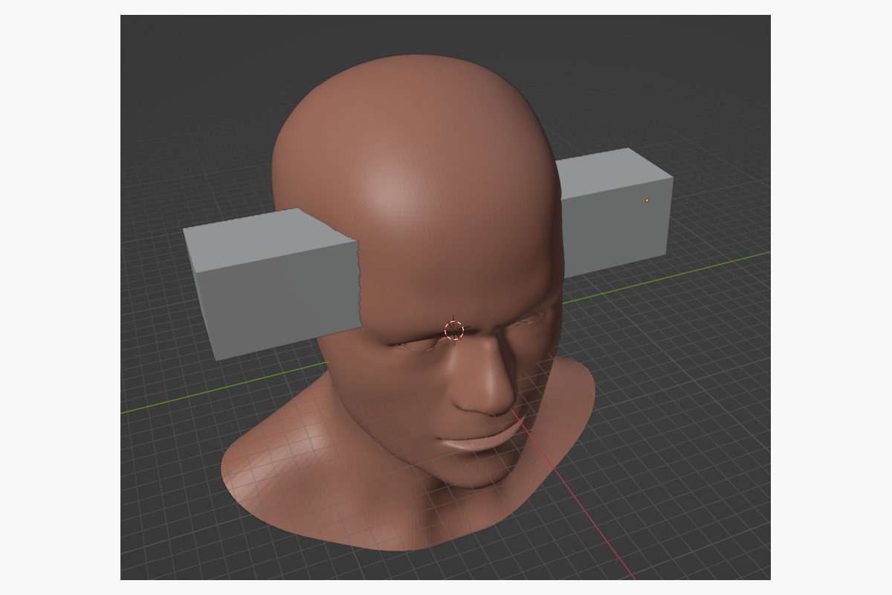
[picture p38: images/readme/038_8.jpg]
布尔修改器演示 3
  
</p>

<p>
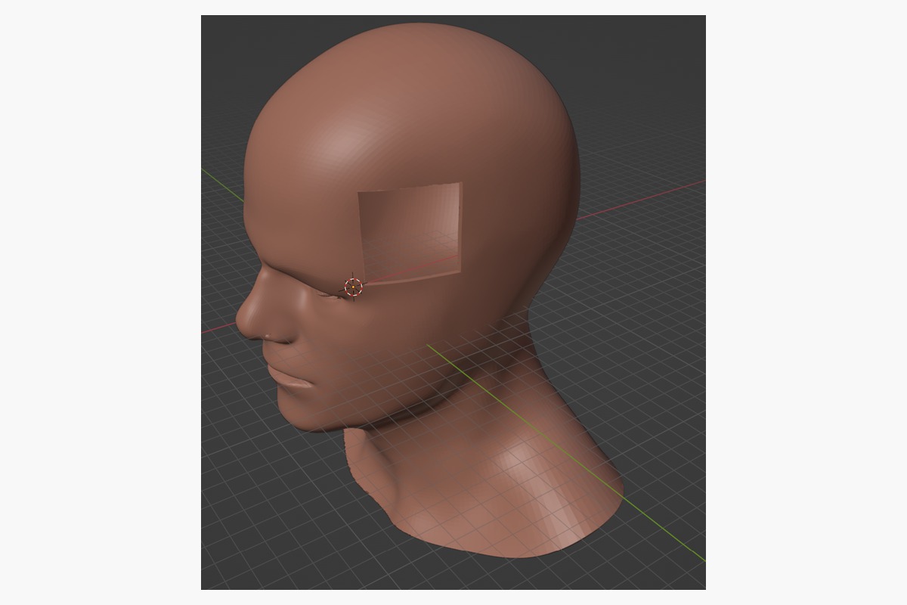
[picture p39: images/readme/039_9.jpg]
布尔修改器演示 4
  
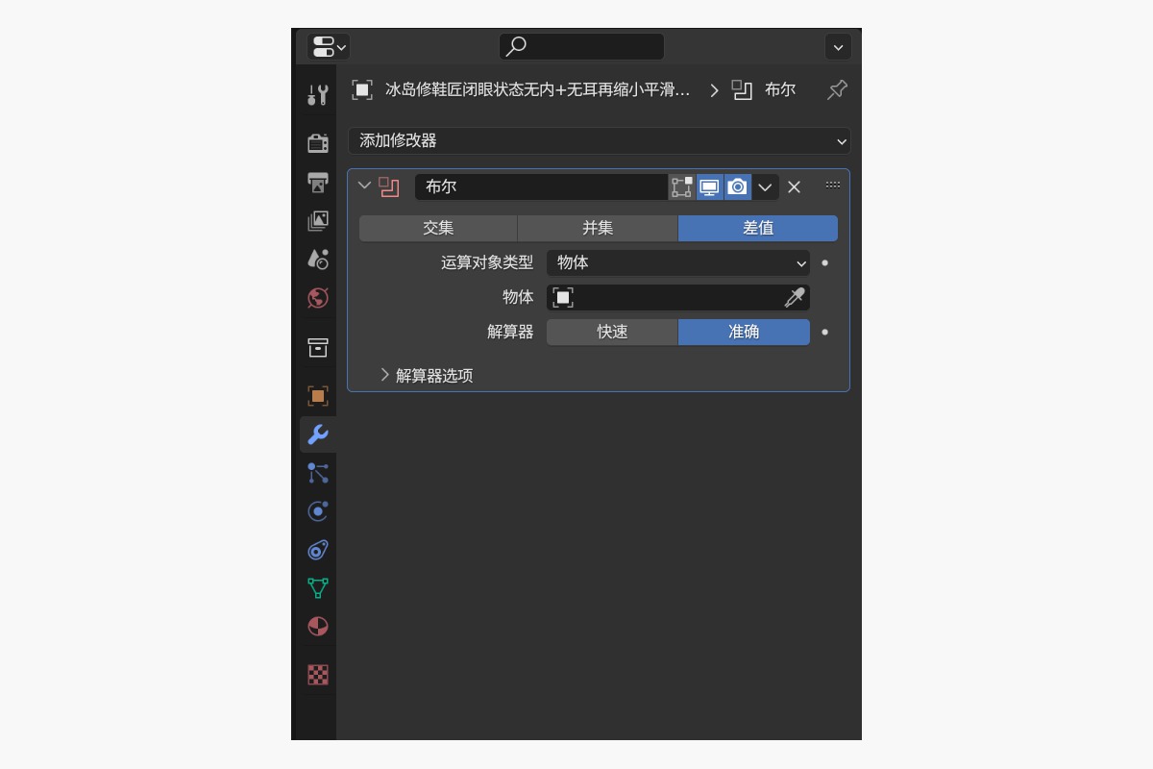
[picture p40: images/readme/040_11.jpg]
布尔修改器演示 5
  
</p>

#### 外壳的实际设计

实际设计中通常需要两部分面壳：上脸部分和下巴部分。因为下巴有两个旋转自由度，所以需要独立出来。

当布尔切割完成后，可以按 `Tab` 进入编辑模式，选中上脸壳的一个点后按 `A` 全选关联点，再右键选择“分离选中项”，即可将两部分独立开来。

<p>
  外壳实际设计 1
  外壳实际设计 2
  外壳实际设计 3
  外壳实际设计 4
</p>

#### 外壳连接部分

外壳需要和 Blender 中导入的原机械结构进行物理连接。本项目采用的是简单的螺栓连接，并直接在 Blender 中完成连接结构的设计。

<p>
  外壳连接结构 1
  外壳连接结构 2
</p>

#### 外壳磁吸部分

为了方便面具摘取和复用，外壳上均匀分布了一些磁吸孔位。

<p>
  外壳磁吸孔位 1
  外壳磁吸孔位 2
</p>

图 18 中的四个槽位预留给眉部上方的拉线自由度，设计成凹槽形式，为拉线提供导向。这个设计参考了清华大学表情机器人 Morphene。

<p>
  眉部拉线导向槽
</p>

设计外壳时，需要将整体 STL 放入 Blender 中进行位置比对，防止出现干涉。需要挖去的位置和挖去多少都比较依赖具体结构，个性化较强，需要根据自己的机构自行设计。

## 4. 硅胶皮肤模具设计

硅胶皮肤的制作通常需要依靠模具，一般使用内外模具。这里将最终用于呈现硅胶外表面的模具称为外模具，也就是最终示人面的那一侧。

整体思路是：制作外壳时使用的无厚度模型，既是外壳的参考，也是内模具的参考；在此基础上整体放大，即可得到外模具。

具体操作方式可以很多样。这里主要记录本项目中的基本思路和关键步骤，不对中间所有建模细节展开。

### 4.1 预处理

为了防止穿模，需要对初始模型进行一定处理，并加上底座。预处理尽量只针对内模具，因为需要确保最终外形一致，所以外模具不建议随意改变。

<p>
  硅胶模具预处理
</p>

### 4.2 磁铁

磁铁分为固定部分和运动部分。固定部分在外壳设计时已经确定位置，因此同样需要用到内模具上；运动部分则通过和模型进行比对，确定几个运动位置的磁铁。

本机器人的面部驱动使用的是磁吸方式。

<p>
  磁铁设计 1
  磁铁设计 2
  磁铁设计 3
</p>

### 4.3 整体处理

模具上添加了用于开模的把手和用于定位的球槽。

<p>
  模具整体处理
</p>

### 4.4 外模具设计

外模具设计不在这里展开细说，主要展示最终设计效果。

<p>
  外模具设计
</p>

### 4.5 整体效果

<p>
  硅胶模具整体效果
</p>

## 5. 其他说明

Blender 开源模型本身提供了眼睛、牙齿和舌头模型，并且这些模型可以用于比对设计是否精准。这对不会曲面建模的设计者非常有利。

本文提供的开源模型仍然需要一定处理，不能简单理解为“直接套用即可完成机器人脸部设计”。它更适合作为可靠的外形参考、空间参考和后续建模基础。

<p>
  眼睛牙齿舌头模型 1
  眼睛牙齿舌头模型 2
  眼睛牙齿舌头模型 3
</p>

<p>
  眼睛牙齿舌头模型 4
  眼睛牙齿舌头模型 5
  眼睛牙齿舌头模型 6
</p>

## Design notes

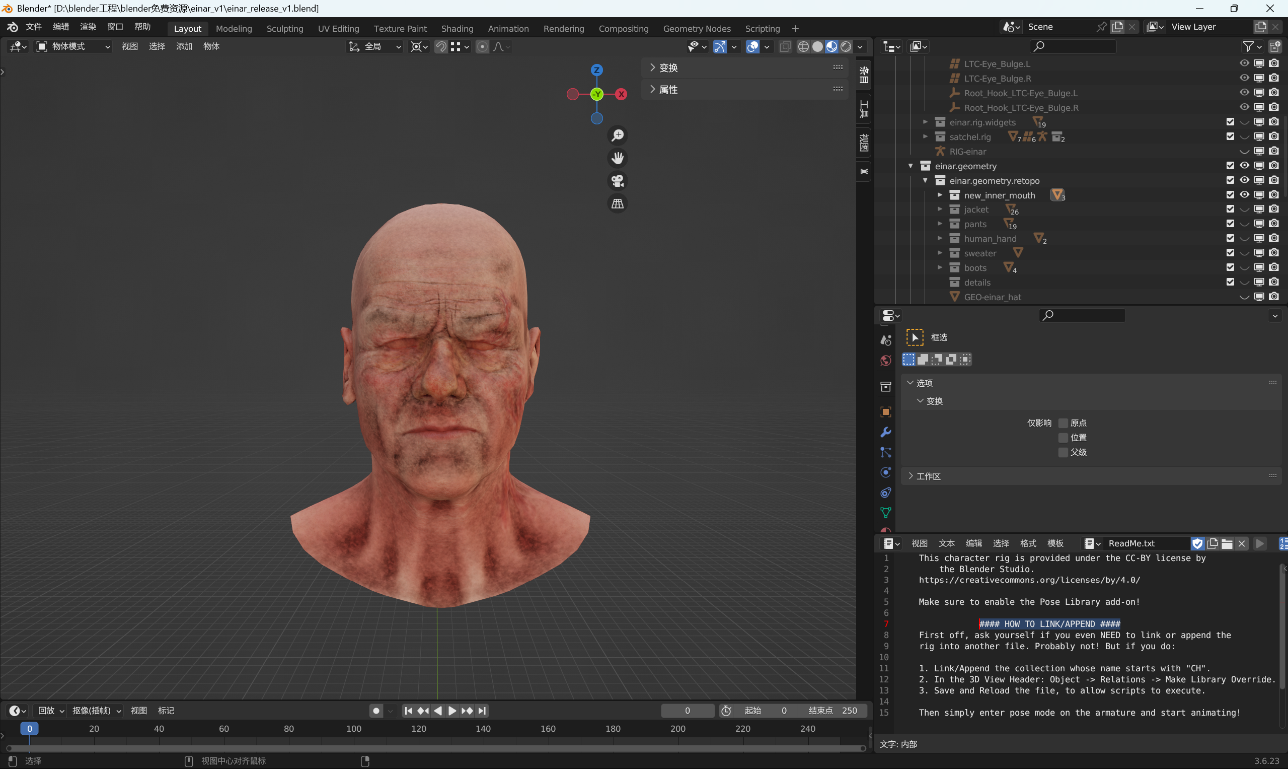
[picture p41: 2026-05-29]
images/blender8.png

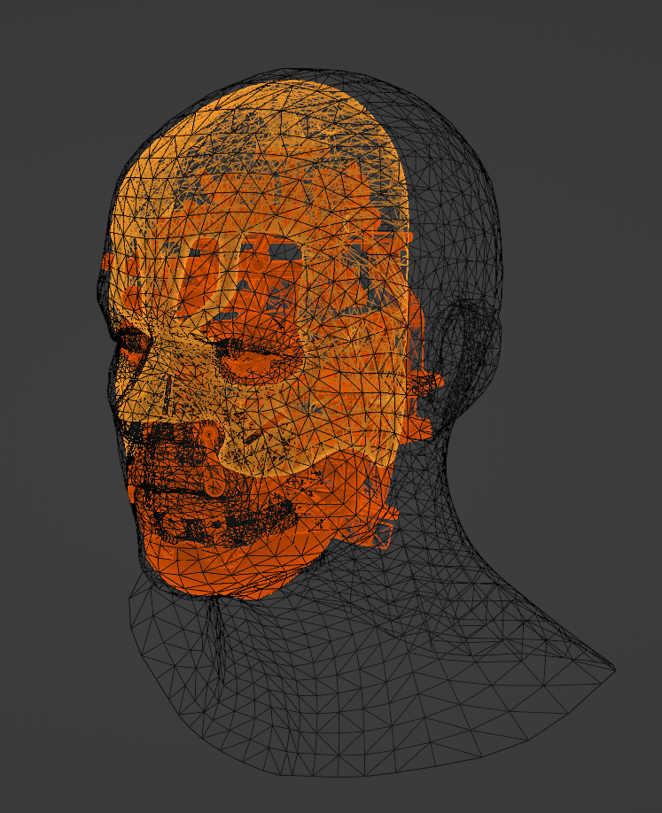
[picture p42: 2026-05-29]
images/blender3.png

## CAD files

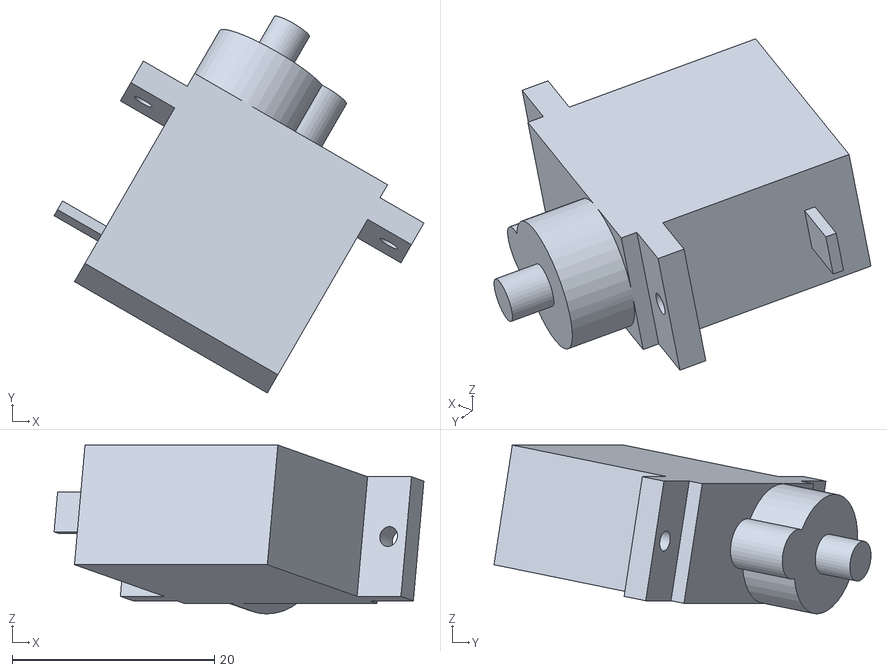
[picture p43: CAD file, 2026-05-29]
full_assembly_stl/full assembly - 【2025927】【嘴部】-1 {BD}MG90S舵机-3.STL
36.5 x 37.2 x 16.7

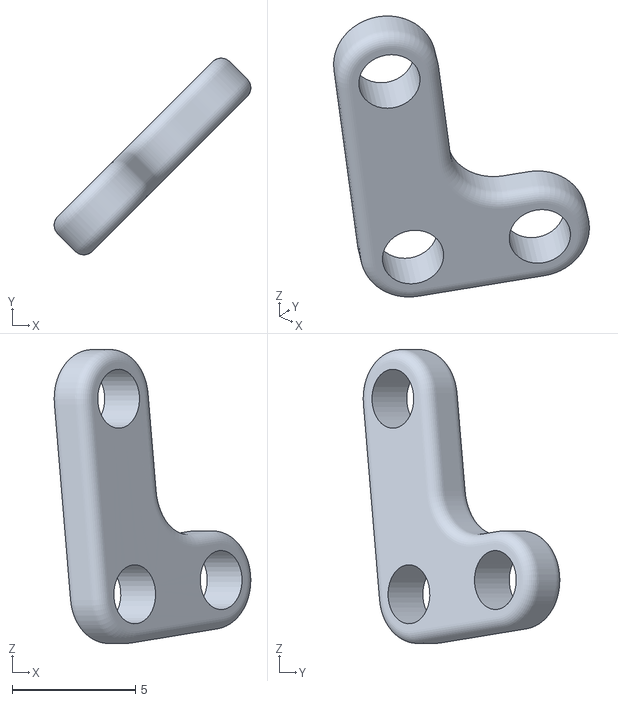
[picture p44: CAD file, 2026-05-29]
full_assembly_stl/full assembly - 【2025927】【嘴部】-1 【2025927】【嘴部】【右上唇部平行连杆1】-1.STL
7.99 x 7.99 x 11.9

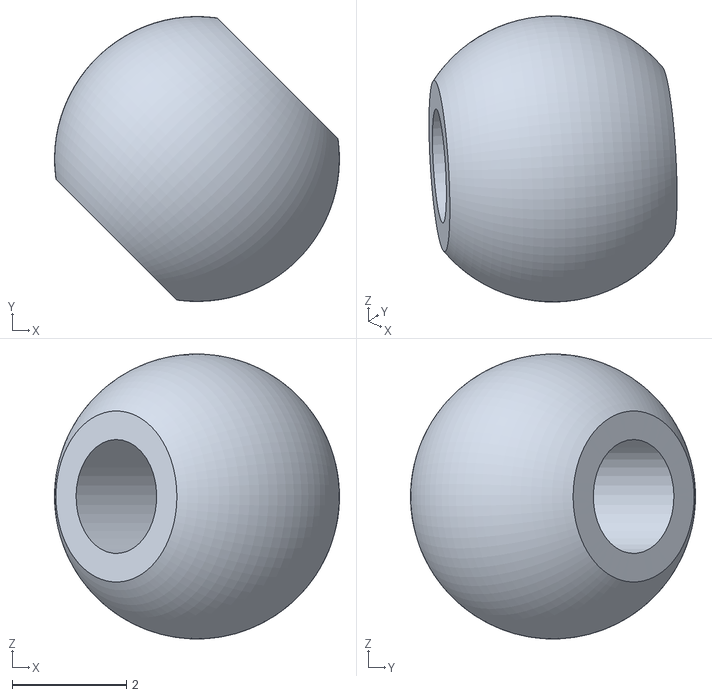
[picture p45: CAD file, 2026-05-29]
full_assembly_stl/full assembly - 【2025927】【嘴部】-1 球头球DIY1749-1.STL
5.00 x 5.00 x 4.99

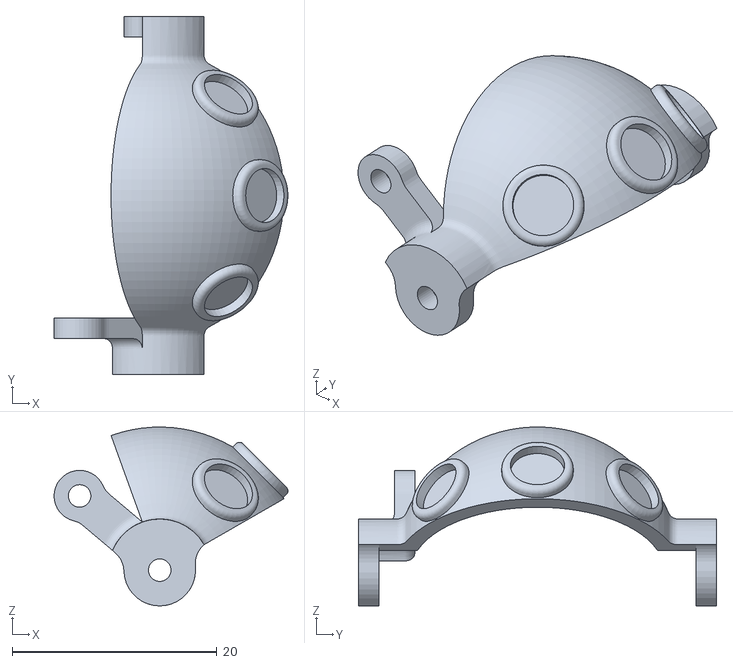
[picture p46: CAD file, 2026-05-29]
full_assembly_stl/full assembly - 【2025927】【眼部】【上眼睑】无扇面-1.STL
22.9 x 35.0 x 17.5

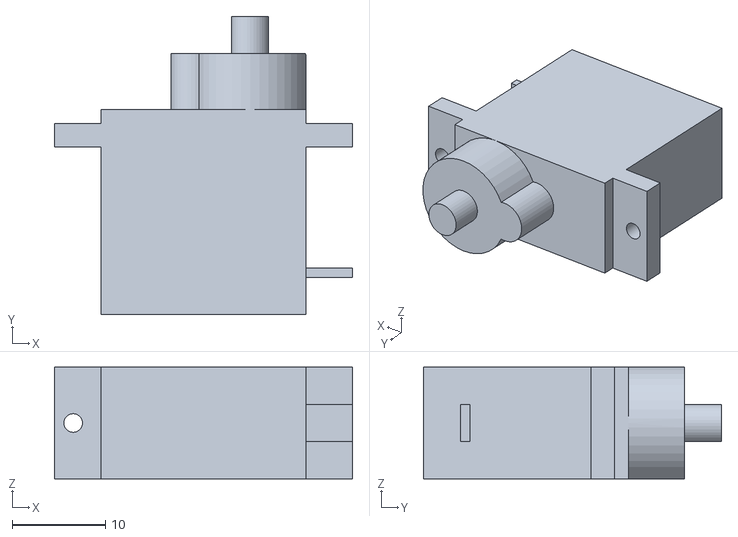
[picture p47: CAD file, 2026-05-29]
full_assembly_stl/full assembly - 【2025927】【眉部】-1 {BD}MG90S舵机-3.STL
32.0 x 32.0 x 12.0

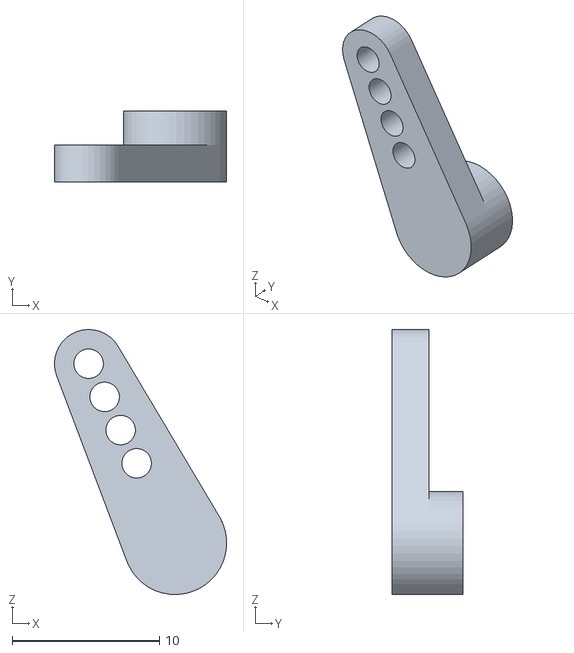
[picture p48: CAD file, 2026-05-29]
full_assembly_stl/full assembly - 【2025927】【眼部】-1 （猎鹰模型舵机工厂）21T金属舵臂-1.STL
11.7 x 4.80 x 18.0

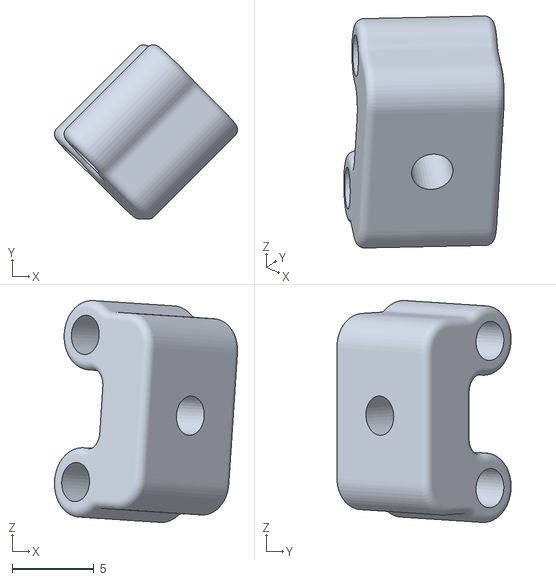
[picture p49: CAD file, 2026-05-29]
full_assembly_stl/full assembly - 【2025927】【嘴部】-1 Mirror【2025927】【嘴部】【左下唇部平行连杆3】-2.STL
11.2 x 10.6 x 13.5

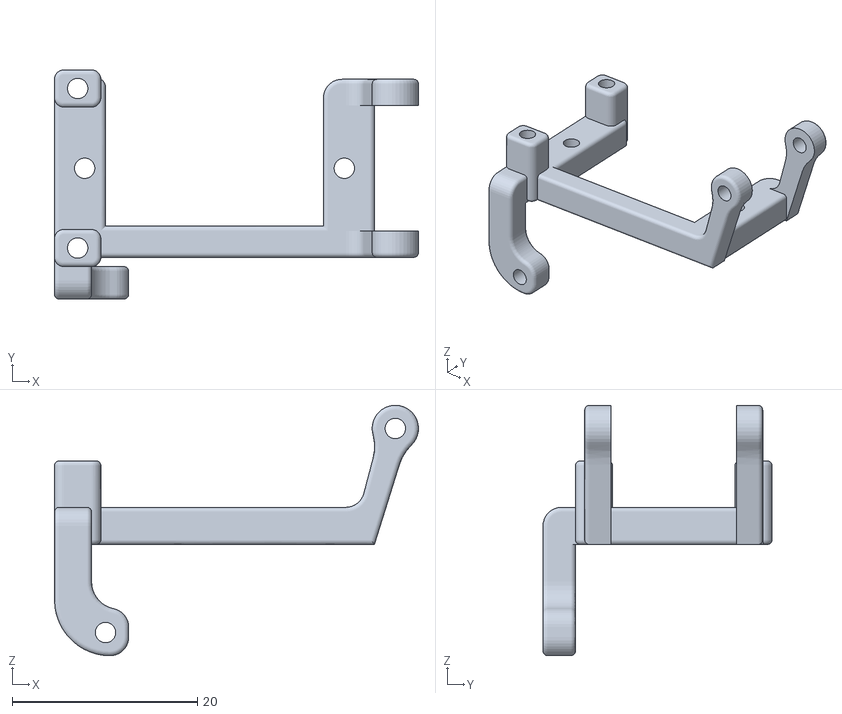
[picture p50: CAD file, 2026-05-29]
full_assembly_stl/full assembly - 【2025927】【眼部】-1 【2025927】【眼部】【眼球偏航舵机支架】-1.STL
39.2 x 24.7 x 27.0

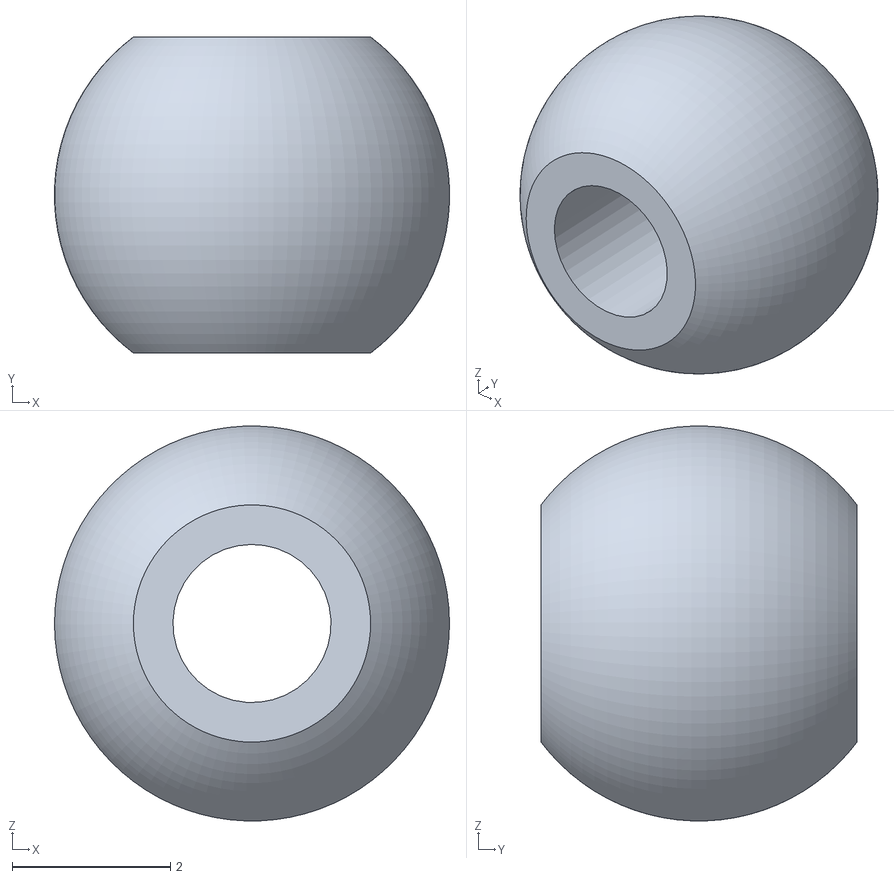
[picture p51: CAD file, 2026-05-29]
full_assembly_stl/full assembly - 【2025927】【眼部】-1 球头球DIY1749-3.STL
5.00 x 4.00 x 4.99

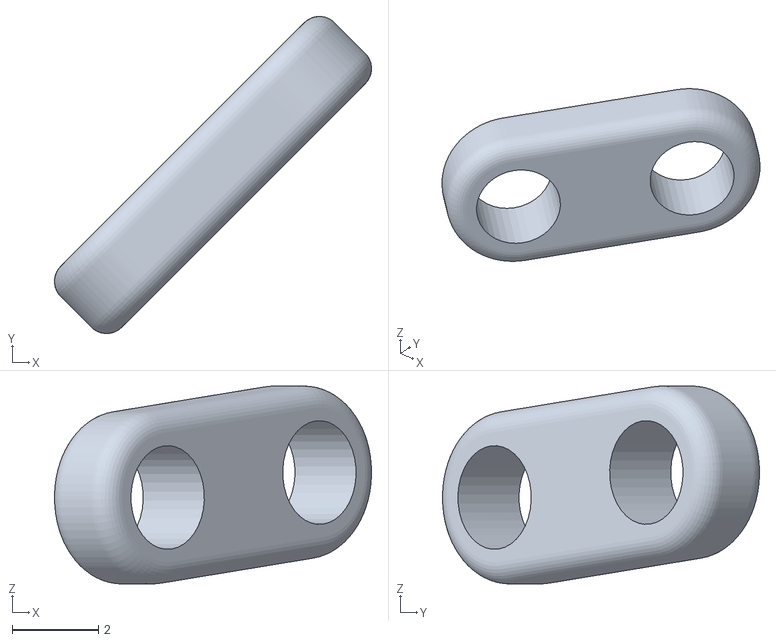
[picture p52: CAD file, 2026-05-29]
full_assembly_stl/full assembly - 【2025927】【嘴部】-1 【2025927】【嘴部】【右上唇部平行连杆2】-2.STL
7.34 x 7.34 x 4.58

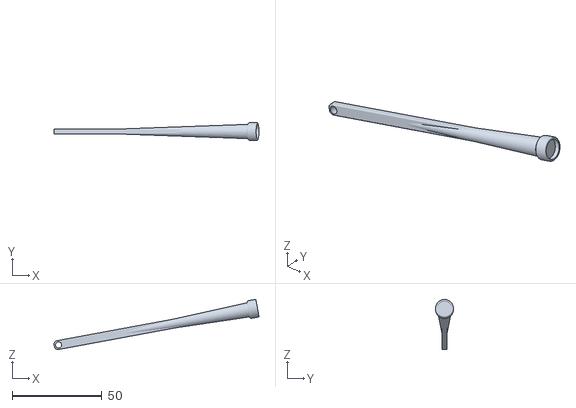
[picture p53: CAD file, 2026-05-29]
full_assembly_stl/full assembly - 【2025927】【嘴部】-1 【2025927】【嘴部】【中上唇部输出连杆】-2.STL
114.0 x 10.0 x 27.9

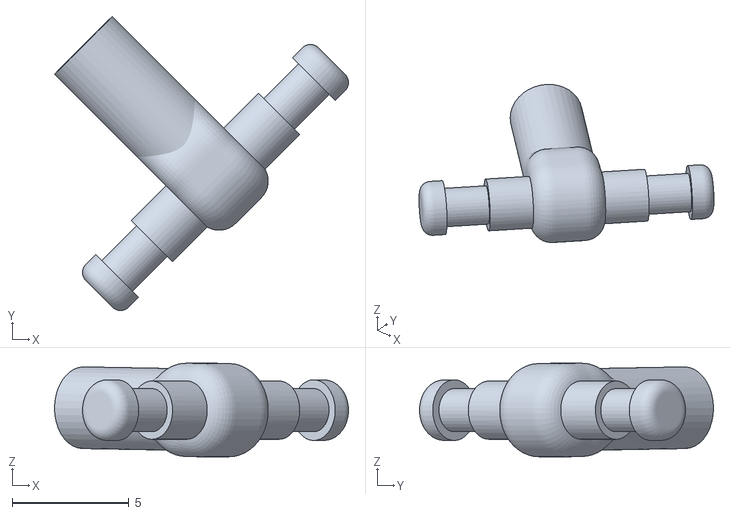
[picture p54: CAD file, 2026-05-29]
full_assembly_stl/full assembly - 【2025927】【嘴部】-1 【2025927】【嘴部】【右上唇部连杆】【一体式转轴】-2.STL
12.6 x 12.6 x 4.01

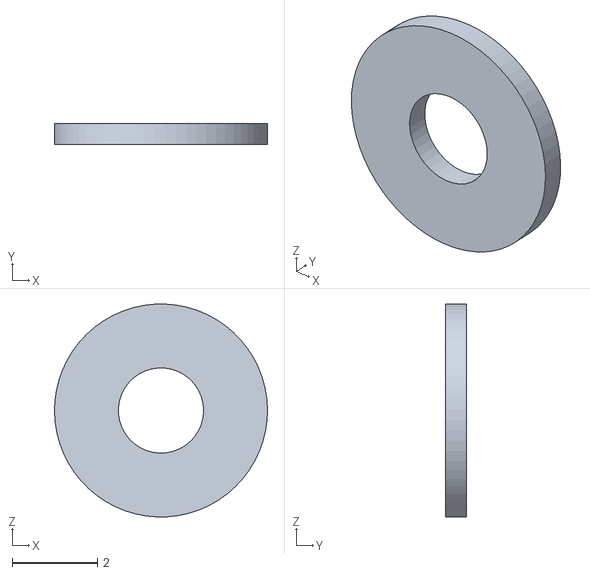
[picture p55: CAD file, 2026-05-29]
full_assembly_stl/full assembly - 【2025927】【眼部】-1 M2X0.5垫片-3.STL
5.00 x 0.5 x 5.00

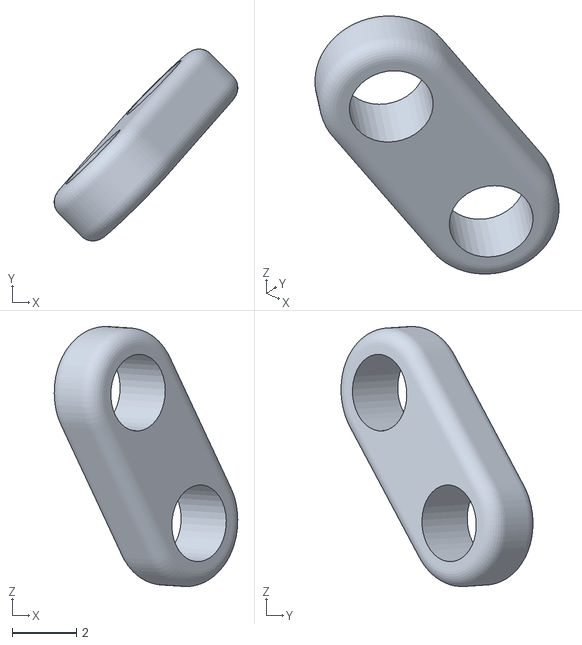
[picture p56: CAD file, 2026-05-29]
full_assembly_stl/full assembly - 【2025927】【嘴部】-1 【2025927】【嘴部】【右下唇部平行连杆2】-1.STL
5.73 x 5.99 x 8.12

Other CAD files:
full_assembly_stl/full assembly - 【2025927】【眼部】-1 {BD}MG90S舵机-3.STL
full_assembly_stl/full assembly - 【2025927】【眉部】-1 M2X0.5垫片-11.STL
full_assembly_stl/full assembly - 【2025927】【嘴部】-1 金属球头-2.STL
full_assembly_stl/full assembly - 【2025927】【眉部】-1 5_2磁铁-2.STL
full_assembly_stl/full assembly - 5_1.5磁铁-1.STL
full_assembly_stl/full assembly - 5_1.5磁铁-10.STL
full_assembly_stl/full assembly - 5_1.5磁铁-11.STL
full_assembly_stl/full assembly - 5_1.5磁铁-12.STL
full_assembly_stl/full assembly - 5_1.5磁铁-2.STL
full_assembly_stl/full assembly - 5_1.5磁铁-3.STL
full_assembly_stl/full assembly - 5_1.5磁铁-4.STL
full_assembly_stl/full assembly - 5_1.5磁铁-5.STL
full_assembly_stl/full assembly - 5_1.5磁铁-6.STL
full_assembly_stl/full assembly - 5_1.5磁铁-7.STL
full_assembly_stl/full assembly - 5_1.5磁铁-8.STL
full_assembly_stl/full assembly - 5_1.5磁铁-9.STL
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

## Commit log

2026-05-29 Initial open source materials
    [full assembly - 5_1.5磁铁-1.STL, full assembly - 5_1.5磁铁-10.STL, full assembly - 5_1.5磁铁-11.STL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]
2026-05-29 Move STL files into full assembly folder
    [full assembly - 5_1.5磁铁-1.STL, full assembly - 5_1.5磁铁-10.STL, full assembly - 5_1.5磁铁-11.STL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]
